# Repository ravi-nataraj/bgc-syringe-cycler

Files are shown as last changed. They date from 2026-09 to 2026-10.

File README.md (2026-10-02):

# BGC Syringe Cycler

Ten-station pneumatic fatigue cycling fixture for balloon guide catheter inflation testing. A single 5/2 solenoid valve drives ten double-acting air cylinders in parallel, each actuating a 1 mL Merit Medical Medallion syringe. Pusher and mount spacing fixes the stroke to displace ~0.6 mL per cycle.

The cycling regime is adapted from ISO 10555-4:2023 Annex B (balloon
fatigue / repeated inflation). Annex B is written for dilatation
balloons and cycles to rated burst pressure; a balloon guide catheter is specified by recommended inflation volume rather than RBP, so the fixture cycles a fixed displaced volume instead. Annex B's default of 10 cycles is likewise adapted — the fixture defaults to 20 — which the standard permits where supported by risk assessment.

Cycle timing is configurable to accommodate different test fluids —
viscous media such as contrast refill the syringe more slowly than
saline or DI water. Timing and cycle count can be set from any device over WiFi, or the fixture can be run from a single button using its DI water / saline defaults (60s on, 10s off, 20 cycles).
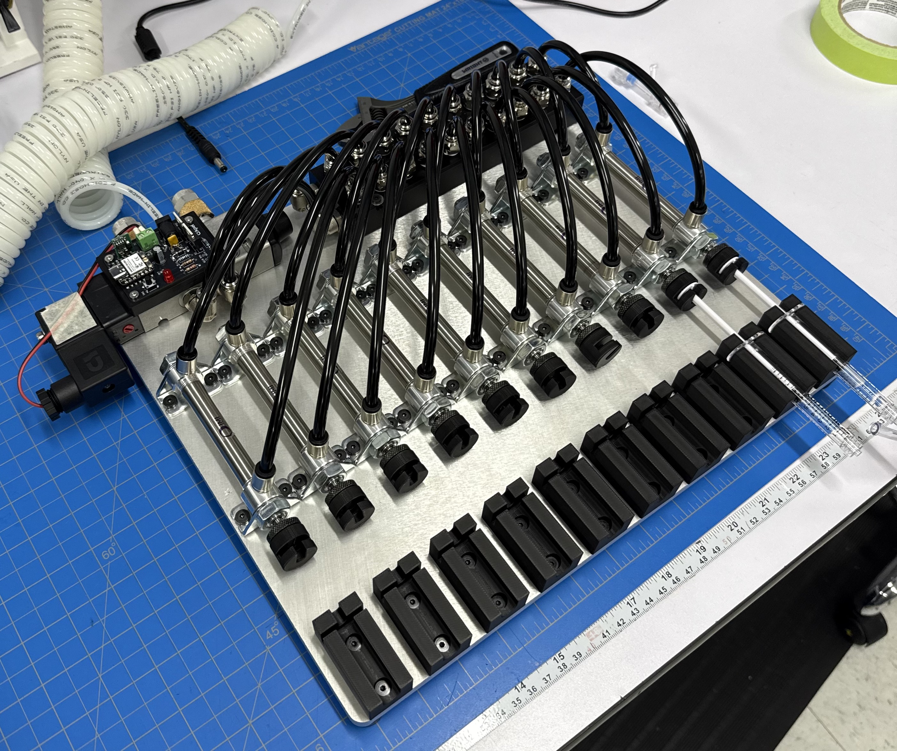
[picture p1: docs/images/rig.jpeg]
The assembled rig


---

## What it does

A run repeats one cycle: all ten cylinders extend, hold, retract, hold.
Defaults are 60 s extended, 10 s retracted, 20 cycles — about 23 minutes.

The cylinders are plumbed in parallel off two distribution manifolds, so
they move together. The controller switches a single valve coil, so
station count is a pneumatic change, not an electrical one.

---

## Running it

### From the button

Power the PCB from a 12 V DC supply (2.5 mm barrel jack, 1 A min).
Short-press the button on the control board to start. The run uses the
current settings and stops on its own. Defaults are 60 s extended,
10 s retracted, 20 cycles.

To abort mid-run, **press and hold the button for 1 second.** The valve
de-energizes immediately and the cylinders retract. A short press during
an active run does nothing, by design.

To change timing or cycle count, see the next section.

### From any device

1. Join the WiFi network **`walrus`**, password **`walrus123`**
2. Open a browser to **192.168.4.1** (add `http://` if the browser tries
to search instead of navigate).
3. Set extend time, retract time and cycle count, then **Save**
4. Press **Start run**

The page shows live status while the fixture runs: which cycle, whether
it is extended or retracted, and time remaining.

Settings lock while a run is in progress. Press **Stop and reset**, or
hold the board button, to unlock them.

Your phone will report "no internet connection" — expected, since the
board is its own access point. If your phone drops the network
automatically, tell it to stay connected when prompted.

The run continues if you disconnect. Reconnect any time to see live
status or stop the run.

### Status LED

| LED | Meaning |
|---|---|
| Off | Idle, waiting |
| Solid | Extended |
| Blinking | Retracted, between cycles |

### Defaults

Settings are held in RAM only. **Cutting power returns the fixture to
60 s / 10 s / 20 cycles**, so the next user always starts from a known
configuration. There is also a *Restore defaults* button on the web
page.

---

## Setting up the pneumatics

| Setting | Value |
|---|---|
| Supply pressure | 60 psi |
| Valve minimum | 44 psi — do not go below this |
| Valve maximum | 145 psi |
| Cylinder | 7/16" bore, 2" stroke |

Set the regulator to **60 psi**. The valve will not shift reliably below 44 psi, so watch the gauge during a ten-cylinder actuation and confirm it does not dip toward that floor. If it does, raise the supply pressure.

Stroke speed is set by the meter-out flow controls on the valve's two exhaust ports, not in firmware.

**Verify stroke before the first run.** The printed pusher bottoms
against the stationary mount, which fixes delivered volume at ~0.6 mL. Cycle once dry and confirm the pusher contacts the mount versus if plunger reaches the end of the barrel.

---

## Repository layout

```
bgc-syringe-cycler/
├── docs/
│   ├── images/                          photos and reference images
│   ├── design-notes.md                  reasoning behind major decisions
│   └── firmware-setup.md                Arduino IDE and board setup
├── firmware/
│   └── syringe_cycler_wifi_volatile.ino
├── hardware/
│   ├── gerbers/                         fabrication output, as ordered
│   ├── images/                          board renders and layout
│   ├── kicad/                           schematic, PCB, dependent libraries
│   └── snoid-swt-BOM.csv                control board bill of materials
├── mechanical/
│   ├── step/                            neutral CAD exports
│   ├── sw-pack-n-go/                    SolidWorks source
│   ├── bgc-inflation-fatigue-assy.pdf   assembly drawing
│   └── mechanical-BOM.csv               fixture bill of materials
├── .gitignore
├── LICENSE
└── README.md
```

Hardware, firmware, and mechanical source for the fixture, plus the
build and setup documentation.

---

## Control board

Custom two-layer PCB ordered from JLPCB. A XIAO ESP32-C3 sits in a socket and switches the 12 V valve coil through a logic-level MOSFET.

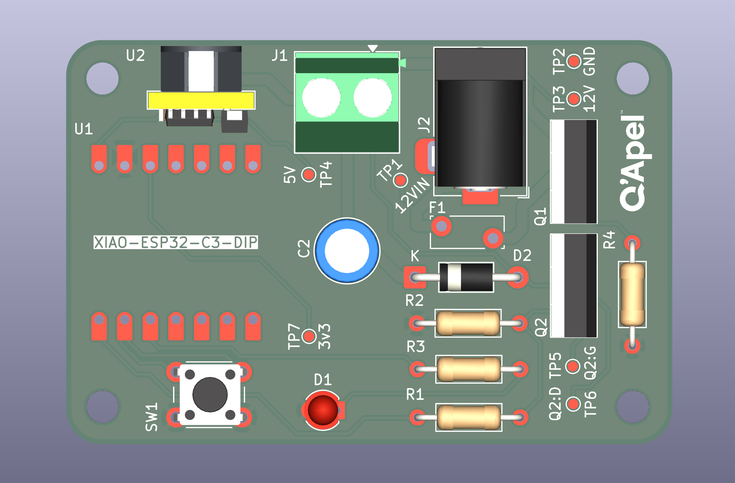
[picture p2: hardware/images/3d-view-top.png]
custom-PCB


| Function | Part |
|---|---|
| MCU | Seeed XIAO ESP32-C3, socketed |
| Valve switch | IRLZ44N, low-side |
| Flyback | 1N4007 across the coil |
| Reverse protection | IRF9540N P-channel, high-side |
| Overcurrent | 0.9 A resettable polyfuse |
| 5 V supply | OKI-78SR-5, switching, TO-220 pinout |
| Input | 12 V, 5.5 × 2.5 mm barrel jack, centre positive |

Seven test points are brought out: 12VIN, 12V, 5V, 3V3, GND, GATE and
DRAIN. See `docs/troubleshooting.md` for what to expect at each.

---

## Building the firmware

Arduino IDE with the ESP32 board package installed.

| Setting | Value |
|---|---|
| Board | XIAO_ESP32C3 |
| USB CDC On Boot | **Enabled** — required, or Serial does nothing |
| Upload spesed | 921600 |
| Serial monitor | 115200 |

Program the XIAO out of its socket, plugged straight into USB.

Serial commands also work: `E60` extend seconds, `R10` retract seconds,
`C20` cycle count, `S` start, `X` stop, `D` restore defaults.

---

## Bringing up a new board

Work through these in order.

1. **Unpowered.** Check continuity between +12 V and GND — should be
   open. A beep means a short; find it before applying power.
2. **12 V in, XIAO out of its socket.** Meter TP4 for 5.00 V.
3. **Power down, insert the XIAO, power up.** The serial banner should print and the LED should respond to the button.
4. **Connect the coil.** Listen for two clicks per cycle, one on and
   one off. No air yet.
5. **Connect air** at 60 psi and run three cycles before committing to a full run.

---

## Known limitations

- **No independent station control.** All ten cylinders actuate together from a shared supply. A single station cannot be paused, removed, or run on a different profile mid-test.
- **Ten units per run.** Each run tests ten units (one lot). A 29-unit attribute sample therefore takes three runs (10/10/9), with one station left empty on the final run.
- **Open-loop timing.** Stroke timing is fixed in firmware. The fixture does not confirm that each cylinder reached its end of travel, so a stalled or short-stroked station will not be flagged. Verify stroke by visual inspection.
- **Aggressive return stroke.** The return stroke can retract the plunger fast enough to pull the white plunger rod out of the plunger stopper. Inspect plunger assemblies periodically during long cycle runs.
- **Limited network security.** The WiFi access point is protected only by a shared password and has no user authentication or access logging. It is intended as a DV bench fixture, not a secured or validated instrument.

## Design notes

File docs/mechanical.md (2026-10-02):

# Mechanical

The fixture cycles ten 1 mL syringes in parallel for balloon guide catheter inflation fatigue testing. Each air cylinder drives a printed pusher against a syringe plunger. The barrel is held in a fixed printed holder. All ten cylinders are plumbed through two manifolds to one 5/2 solenoid valve, so every station actuates together.

The source drawing is `bgc-inflation-fatigue-assy.pdf`.
## Bill of Materials

| Item | Part Number | Description | Qty |
|---|---|---|---|
| 1 | 6498K604 | Round body air cylinder mount **[verify]** | 10 |
| 2 | 4952K126 | Foot bracket, 7/16" | 20 |
| 3 | 1ml-syringe-push | Syringe pusher (printed) | 10 |
| 4 | stationary-mount | Syringe holder (printed) | 10 |
| 5 | 5779K246 | Push-to-connect fitting | 20 |
| 6 | 92220A162 | Low-profile SHCS | 60 |
| 7 | baseplate | Baseplate (MIC-6 aluminum, machined) | 1 |
| 8 | 5469K191 | Right-angle flow manifold | 2 |
| 9 | 6124K277 | 5/2 solenoid valve | 1 |
| 10 | 7397N268 | Push-to-connect fitting | 4 |
| 11 | 53535A11 | Rubber foot | 4 |
| 12 | 7397N239 | Push-to-connect fitting | 20 |
| 13 | 90107A010 | 316 SS washer | 7 |
| 14 | 92220A157 | Low-profile SHCS | 7 |
| 15 | pcb-mount_v1 | PCB mount on solenoid (printed) | 1 |
| — | 9164K12 | Exhaust flow control, slotted screw, 1/4 NPT (not on drawing) | 2 |

Part numbers are from McMaster-Carr unless noted.
## Custom Parts

- **Baseplate:** MIC-6 aluminum, 13.976 × 11.811 in.
  - Station pitch is 1.384 ±.001.
  - 40X 10-32 holes for the cylinder brackets, 20X 10-32 for the syringe holders, and 11X 8-32 for the manifolds and valve **[verify]**.
- **Syringe holder:** FDM (PLA, ABS, or PETG), ±.020.
  - Ø5.0 mm barrel slot with a Ø9.8 mm flange pocket.
  - 2X counterbored holes for 10-32.
- **Syringe pusher:** FDM, ±.020, bore axis vertical, 4 perimeters minimum.
  - A 0.118 in slot captures the plunger flange.
  - 8-32 heat-set insert for the cylinder rod.
- **PCB mount:** FDM, 65.5 × 45.5 mm.
  - 4X M3 heat-set inserts.
  - Mounts directly to the solenoid body.

## Pneumatics

Regulated supply air feeds the 5/2 solenoid valve. The valve's two outputs each feed a manifold, one for extend and one for retract. Each manifold has 10 outlets, one per cylinder, so every cylinder has an extend line and a retract line. All air lines are 1/4" OD tubing.

Stroke speed is set by the two 9164K12 meter-out flow controls in valve exhaust ports 3 and 5. Each control sets the speed of one stroke direction.

**Setting the return speed:**

1. Retract using the manual override and find which exhaust port vents. That port controls the return.
2. Start with that port's flow control about ¾ closed. Open it a ¼ turn at a time until the cycle time is met.
3. Lock it and record the number of turns out from fully closed.
4. Run at least 200 cycles and confirm the plunger rods stay seated.

## Known Limitations

- **No independent station control.** All stations actuate together.
- **Open-loop stroke.** There are no end-of-travel sensors, so verify stroke visually.
- **Plunger separation.** A fast return can pull the white plunger rod out of the stopper. The return-side flow control limits this.
- **Uneven speed between stations.** Stations with lower friction return faster than others. Per-cylinder flow controls would even this out.
- **Tight bracket spacing.** The 10-32 bracket holes leave little clearance between cylinder brackets.
  - *Next revision:* respace the hole pattern. The station pitch and the holder pattern must change to match.
- **Printed parts.** They are uninspected at ±.020. Ream bores to fit and replace worn pushers.

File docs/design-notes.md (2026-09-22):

# Design Notes

Why the fixture is built the way it is. The README covers what it does
and how to run it; this file covers the reasoning, so that anyone
changing something knows what constraint they might be breaking.

---

## Pneumatics

### Why a 5/2 spring-return valve

The cylinder is double-acting, so it needs air on both sides — a 5/2
valve is the standard part for that. Spring return means a single coil
and a single control signal, and the fail-safe state on power loss is
retracted.

A bistable double-solenoid valve was considered. It only needs a brief
pulse to shift, so total coil-on time across a run would drop from 20
minutes to about 2 seconds, and it holds position on power loss. At
2 W the thermal argument does not matter, and retracted is the safer
fail-safe for a syringe, so spring return won.

### Air path

Shop air → filter/regulator (60 psi) → valve inlet

Valve outlet A → manifold A → ten cylinder extend ports
Valve outlet B → manifold B → ten cylinder retract ports

Both valve exhausts → muffler flow controls (meter-out, sets stroke speed)

1/4" OD trunk from valve to manifolds, 1/8" OD branches to cylinders.
Cylinder ports are 10-32.

### Why 60 psi

The valve is pilot-operated — incoming air pressure shifts the spool
and the solenoid only gates the pilot. **Below 44 psi it will not shift
reliably.**

Force is not the constraint. At 60 psi the 7/16" bore produces about
40 N gross, roughly 24 N net after meter-out back pressure, against a
worst-case plunger requirement near 12.6 N. That is around 2× margin,
and more like 4–6× for a typical balloon inflation pressure.

60 psi sits comfortably above the shift threshold while keeping force
modest. The risk to watch is **transient droop**: ten cylinders crack
open simultaneously, the manifold refills, and line pressure dips. If
the gauge dives toward 44 psi during actuation, raise supply pressure
or add a small receiver near the manifold.

### Why a 7/16" bore cylinder

Sized on force, but the real reason it works is that **delivered volume
is set by stroke length, not force**. Surplus force does not push more
fluid; it only has to exceed the resistance.

For a 1 mL syringe, 0.6 mL is about 34 mm of plunger travel. The 2"
stroke covers that with room to spare, and using two-thirds of the
stroke means a ±1 mm stop error is under 3% of dose.

**The surplus force is the hazard.** If the line ever blocks, 40 N on a
17.5 mm² plunger generates roughly 335 psi of fluid pressure — enough
to burst a small balloon or pop a luer-slip joint. Use luer lock, and
rely on the mechanical stop so the fixture delivers a fixed volume
rather than pushing until something fails.

### Why flow control on the exhaust, not the inlet

Meter-out. Throttling the exhaust gives smooth, controlled motion;
throttling the inlet gives jerky, unpredictable strokes. The two
exhaust ports also need silencing — an unmuffled 1.3 Cv valve is loud —
so muffler-flow-control units do both jobs in one body.

Note that exhaust metering controls the **aggregate** of all ten
cylinders, not each one. They will not move in perfect synchrony; the
one with least seal friction moves first. This is acceptable for this
application. Per-cylinder trim would need flow controls at each
cylinder port instead.

### Why tubing size barely matters

The cylinder's own 10-32 ports are the tightest restriction in the
system and cannot be opened up, so upsizing tubing downstream buys
nothing.

The numbers: each cylinder sweeps 0.30 in³, about 0.05 scfm if the
stroke takes a second. Ten cylinders is roughly 0.27 scfm against a
valve rated 43.1 scfm — around 160× more valve than needed.

1/4" OD on the trunk from valve to manifold, 1/8" OD on the branches,
is correct and has margin.

---

## Electronics

### Why low-side switching

The MOSFET sits between the coil and ground. Source is grounded, drain
faces the load. This is the simplest arrangement for a microcontroller
to drive, because the gate voltage is referenced to ground, which the
MCU shares.

**Source must be grounded.** Gate drive is measured gate-to-source, so
if the source floats the gate voltage means nothing. Wiring drain and
source backwards also lets the MOSFET's internal body diode conduct,
which energises the valve permanently and leaves the gate with no
authority at all.

### Why the two gate resistors are different things

**R1, 220 Ω in series.** The gate is a capacitor. At the instant the
pin goes high the gate looks like a short to ground, and without series
resistance the GPIO takes the full inrush. 3.3 V / 220 Ω = 15 mA peak,
comfortably inside spec. The cost is a switching time of a couple of
microseconds, which against a 60 second hold is nothing.

**R2, 10 kΩ pulldown.** During boot the GPIO is a floating input for a
few hundred milliseconds before firmware runs. A floating gate with no
leakage path accumulates stray charge, and if it drifts past the
threshold the valve fires. **On every power-up and every reset —
including each time new firmware is uploaded.** The pulldown gives that
charge somewhere to go.

10 kΩ is the value because it forms a divider with R1 in steady state.
1 kΩ would cost 18% of the gate drive; 10 kΩ costs 2% and still bleeds
charge fast enough.

### Why the flyback diode

The coil stores energy in a magnetic field. Switching it off abruptly
produces V = -L(di/dt), which without a path can reach several hundred
volts across a MOSFET rated for 55 V.

The diode sits **in parallel with the coil**, band toward +12 V. In
normal operation it is reverse-biased and does nothing. At switch-off
it forward-biases and the current circulates in a closed loop through
coil and diode until it decays, clamping the spike to about 12.7 V.

Installed backwards it is a direct short across the supply.

Fitting it at the coil terminals rather than on the PCB catches the
spike at its source. The board has a footprint for it either way.

### Why the P-FET is wired backwards

Reverse-polarity protection. Barrel jacks are physically identical
whether centre-positive or centre-negative, so plugging in the wrong
adapter is easy and would destroy the electrolytic and the regulator.

A series diode would work but costs 0.4–0.7 V continuously. A MOSFET
does it in a few milliohms.

**The wiring is deliberately reversed:**

| Pin | Connects to |
|---|---|
| Drain | input side, from the polyfuse |
| Source | output side, the +12 V rail |
| Gate | ground, through 10 kΩ |

Correct polarity: the body diode conducts first, lifting the source to
about 11.4 V. Gate sits at 0 V, so Vgs ≈ −11.4 V, which is solidly on
for a P-channel. The channel then shorts out its own body diode.

Reverse polarity: the body diode faces the wrong way to conduct, and
the gate ends up positive relative to source, which is off. Two
independent mechanisms both block.

**If wired the intuitive way** — source to input, drain to output — the
body diode would conduct freely on reverse polarity and the protection
would do nothing, while looking perfectly correct on the schematic.
This is the connection most likely to be "corrected" by someone who
does not know why it is like that.

### Why 0.9 A on the polyfuse

The board draws about 320 mA: 167 mA for the coil plus roughly 150 mA
at 12 V to make the XIAO's 5 V.

Sizing rule is 2–3× normal draw. 0.9 A hold gives 2.8× headroom — no
nuisance tripping — and trips at 1.8 A, a fault current the board
survives briefly.

A 1.85 A part was ordered first. It holds until 3.7 A, which is 11×
normal draw and only protects against a hard short. The 0.9 A part is
also physically smaller and uses the same 5.08 mm radial footprint.

Derating matters: at 40 °C the hold current drops to 0.75 A, at 60 °C
to 0.61 A. Still well above 320 mA.

### Why a regulator module and not a designed-in one

The OKI-78SR-5 is a switching regulator in a **three-terminal TO-220
package pin-compatible with a 7805**. It takes 7–36 V in, gives fixed
5 V out at up to 1.5 A, needs no external components, and runs at about
90% efficiency.

That combination removes three problems at once:

- **No switching layout to get wrong.** Inductor placement and feedback
  routing are already solved inside the module.
- **No trimpot.** An adjustable buck module ships at an arbitrary
  voltage, and connecting the XIAO before setting it is the single
  easiest way to destroy the board.
- **No custom footprint.** TO-220 is already in the KiCad library and
  already used for both MOSFETs.

**A linear 7805 is not an acceptable substitute.** Dropping 7 V at the
XIAO's 250–500 mA WiFi transmit peaks means 2–3.5 W in a TO-220, which
hits thermal shutdown. The symptom looks exactly like a random software
reset, which is miserable to diagnose.

### Why the XIAO is socketed

The USB port stays accessible for programming, a damaged module is a
$5 swap rather than desoldering 14 castellated pads, and the module can
move between boards.

Machined round-pin sockets rather than stamped — better contact, and
they survive repeated insertion.

**Assembly note:** plug the two 7-pin sockets onto the XIAO's own pins
first, then drop the whole assembly into the board and solder. That
guarantees the spacing matches the module even if the footprint is
slightly off.

### Why the 100 µF is where it is

Bulk decoupling on the 12 V rail. When the MOSFET turns on, the coil
demands 167 mA instantly, and that current has to travel through cable,
a barrel jack, and PCB traces — all of which have inductance. The rail
sags briefly.

The capacitor supplies that first gulp locally. Without it, a deep
enough dip trips the regulator's undervoltage lockout and brownouts the
XIAO mid-run, which presents as a random crash.

Electrolytic is correct here. Nothing measures its value and its
leakage is irrelevant — the job is cheap farads close to the load.

---

## Firmware

### Why millis() and not delay()

`delay(60000)` would freeze the processor for a minute, during which
the button is unreadable. The abort gesture could not exist.

The loop runs thousands of times per second doing three cheap things:
read the button, check whether the current state's timer has elapsed,
update the LED. Nothing blocks, so the button stays responsive through
the entire run.

The `now - stateEnteredAt` pattern is also overflow-safe. `millis()`
wraps after 49 days and unsigned subtraction still gives the correct
elapsed time across the wrap.

### Why the long press fires on threshold, not release

The abort fires the instant the hold passes one second, rather than
waiting for the button to be let go. The operator gets immediate
feedback and the valve drops the moment they have held long enough.

A flag then suppresses the short press that the release would otherwise
generate.

### Why a short press does nothing mid-run

Two different stop gestures would mean a knocked bench could end a
23-minute test at cycle 17. Stopping requires the deliberate hold.

### Why settings are not saved to flash

An earlier version used the Preferences library, so settings survived a
power cycle. That was changed deliberately.

On shared equipment, a stale setting is worse than an inconvenient one.
If someone sets 5 s / 5 s / 3 cycles for a quick check and walks away,
the next person pressing the button gets 5/5/3 without knowing. Holding
settings in RAM means **power-off always returns the fixture to
60 s / 10 s / 20 cycles**, so the button is predictable for anyone who
did not configure it.

The trade is that a non-default run has to be configured each time the
fixture is powered up. If one non-default configuration becomes the
norm, change `DEF_EXTEND` and friends at the top of the sketch and
re-flash.

### Why an access point and not a WiFi client

The board broadcasts its own network rather than joining an existing
one. No IT involvement, no credentials, no dependence on site coverage,
and the address is always **192.168.4.1** rather than whatever a router
assigns.

### Why the safe state is set first in setup()

`digitalWrite(PIN_VALVE, LOW)` runs before serial, before the button,
before anything. If the board resets mid-run the coil de-energises in
the first microseconds rather than waiting for the rest of
initialisation.

---

## Things deliberately not done

**Independent station control.** Ten cylinders run in parallel off one
valve because the test does not require staggering them. Adding it
would mean ten valves, ten MOSFETs and ten channels — the electronics
scale linearly, but nothing in the protocol asks for it.

**Closed-loop position sensing.** Reed switches on the cylinder barrels
would confirm the piston actually reached each end rather than assuming
it after a timer, and would catch a stuck cylinder during an unattended
run. The spare GPIO exists for this. It was not needed for the initial
protocol.

**Pressure logging.** A transducer on the manifold would record what
supply pressure actually does during a ten-cylinder actuation, which is
currently verified by watching a gauge.

**A discrete 555 version.** Fully designed — CMOS 555 astable at
60 s / 10 s, CD4026 counters driving seven-segment displays, all of it
running directly from 12 V with no regulator. Set aside because the
microcontroller version was already working and is far easier to
reconfigure.

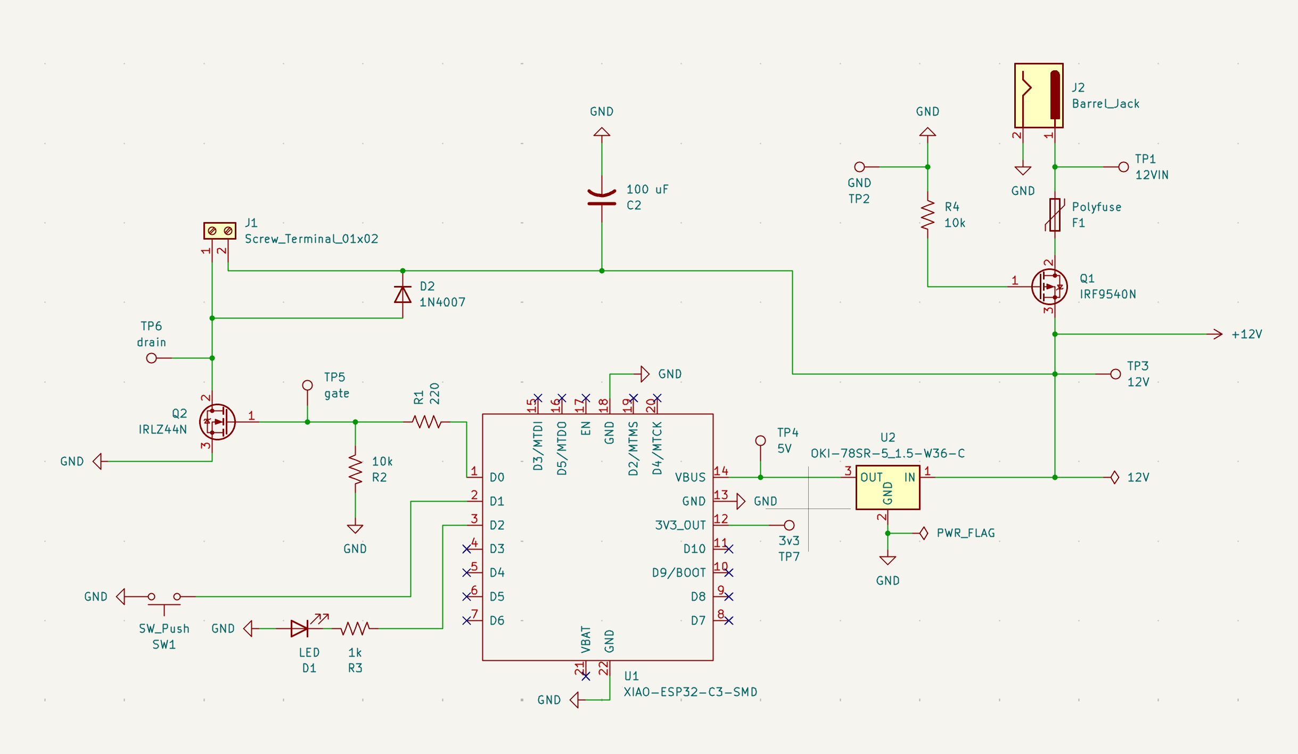
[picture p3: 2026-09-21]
hardware/images/schematic.png

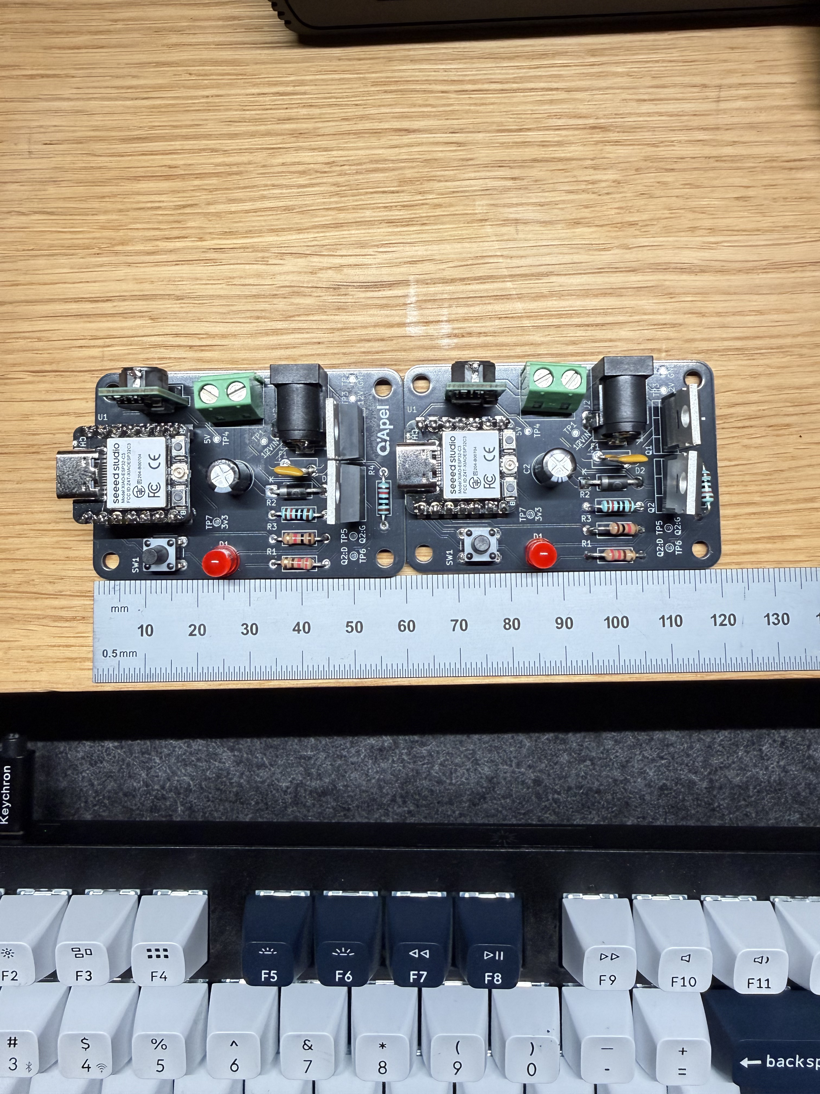
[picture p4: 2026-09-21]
hardware/images/boards-60x40-irl.jpeg

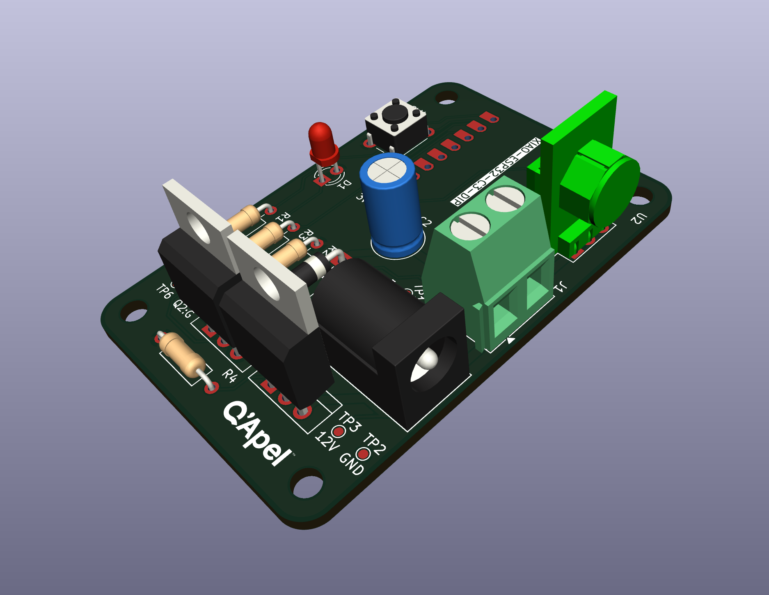
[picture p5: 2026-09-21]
hardware/images/3d-view-iso.png

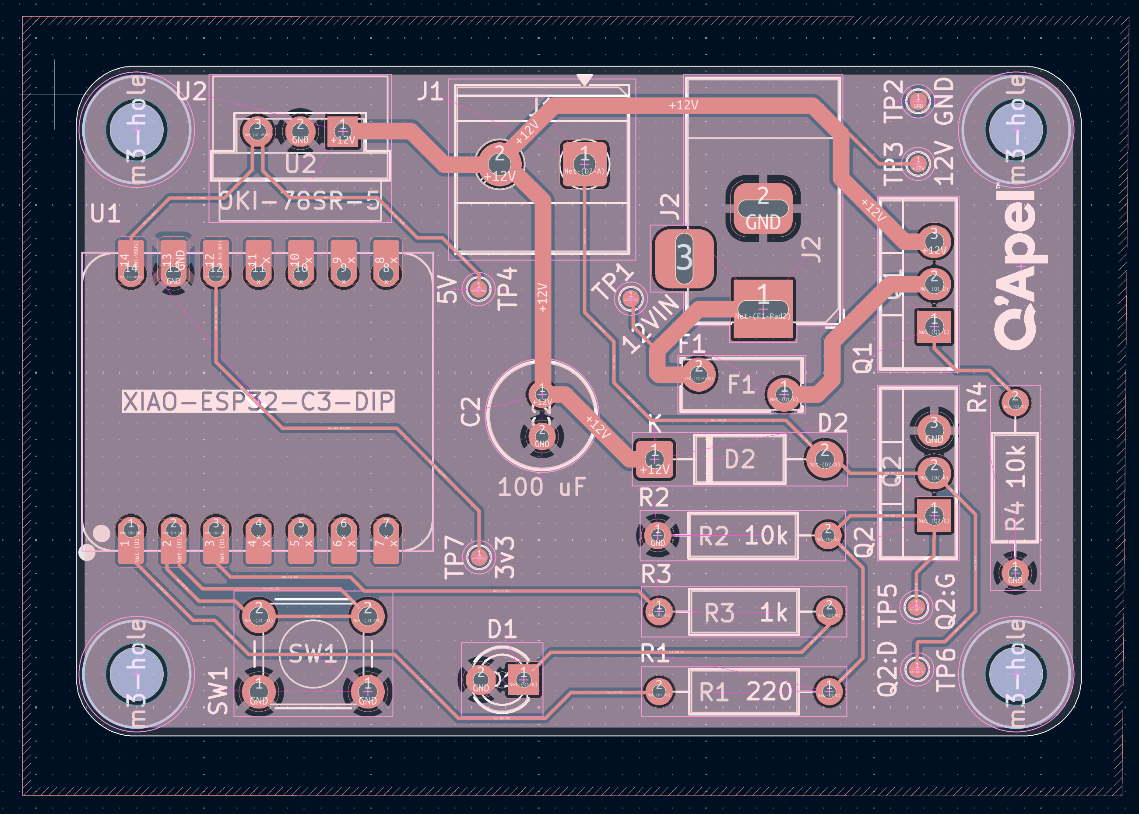
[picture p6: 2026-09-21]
hardware/images/layout.png

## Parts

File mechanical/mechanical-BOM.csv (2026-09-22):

<FONT size=10PTS>ITEM NO. | PART NUMBER | Desc1 | Desc2 | QTY.
1 | 6498K604 | Round Body Air | Cylinder Mount | 10
2 | 4952K126 | Foot Bracket | for 7/16" | 20
3 | 1ml-syringe-push | proximal syringe pusher | n | 10
4 | stationary-mount | distal syringe holder | n/a | 10
5 | 5779K246 | Push-to-Connect Tube | Fitting for Air | 20
6 | 92220A162 | Alloy Steel Low-Profile | Socket Head Screw | 60
7 | baseplate | n/a | n/a | 1
8 | 5469K191 | Anodized Aluminum Right- | Angle Flow Manifold | 2
9 | 6124K277 | Air Directional | Control Valve | 1
10 | 7397N268 | Universal-Thread Push-to- | Connect Tube Fitting | 4
11 | 53535A11 | Rubber | Foot | 4
12 | 7397N239 | Universal-Thread Push-to- | Connect Tube Fitting | 20
13 | 90107A010 | Highly Corrosion-Resistant | 316 Stainless Steel Washer | 7
14 | 92220A157 | Alloy Steel Low-Profile | Socket Head Screw | 7
15 | pcb-mount_v1 | n/a | n/a | 1

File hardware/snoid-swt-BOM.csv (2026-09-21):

Reference | Qty | Value | DNP | Exclude from BOM | Exclude from Board | Footprint | Datasheet
C2 | 1 | 100 uF |  |  |  | Capacitor_THT:CP_Radial_D8.0mm_P3.50mm
D1 | 1 | LED |  |  |  | LED_THT:LED_D3.0mm
D2 | 1 | 1N4007 |  |  |  | Diode_THT:D_DO-41_SOD81_P10.16mm_Horizontal | http://www.vishay.com/docs/88503/1n4001.pdf
F1 | 1 | Polyfuse |  |  |  | Resistor_THT:R_Axial_DIN0207_L6.3mm_D2.5mm_P10.16mm_Horizontal
J1 | 1 | Screw_Terminal_01x02 |  |  |  | TerminalBlock_Phoenix:TerminalBlock_Phoenix_MKDS-1,5-2-5.08_1x02_P5.08mm_Horizontal
J2 | 1 | Barrel_Jack |  |  |  | Connector_BarrelJack:BarrelJack_Horizontal
Q1 | 1 | IRF9540N |  |  |  | Package_TO_SOT_THT:TO-220-3_Vertical | http://www.irf.com/product-info/datasheets/data/irf9540n.pdf
Q2 | 1 | IRLZ44N |  |  |  | Package_TO_SOT_THT:TO-220-3_Vertical | http://www.irf.com/product-info/datasheets/data/irlz44n.pdf
R1 | 1 | 220 |  |  |  | Resistor_THT:R_Axial_DIN0207_L6.3mm_D2.5mm_P10.16mm_Horizontal
R2,R4 | 2 | 10k |  |  |  | Resistor_THT:R_Axial_DIN0207_L6.3mm_D2.5mm_P10.16mm_Horizontal
R3 | 1 | 1k |  |  |  | Resistor_THT:R_Axial_DIN0207_L6.3mm_D2.5mm_P10.16mm_Horizontal
SW1 | 1 | SW_Push |  |  |  | Button_Switch_THT:SW_PUSH_6mm
U1 | 1 | XIAO-ESP32-C3-SMD |  |  |  | Seeed_Studio_XIAO_Series:XIAO-ESP32-C3-DIP
U2 | 1 | OKI-78SR-5_1.5-W36-C |  |  |  | Converter_DCDC:Converter_DCDC_Murata_OKI-78SR_Vertical | https://power.murata.com/data/power/oki-78sr.pdf

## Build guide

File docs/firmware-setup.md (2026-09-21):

# Firmware Setup

How to install the toolchain and flash the XIAO ESP32-C3.

The XIAO does **not** appear in the Arduino IDE out of the box. It ships
inside Espressif's ESP32 board package, which has to be added manually.

---

## 1. Install the Arduino IDE

Download the current version from
[arduino.cc/en/software](https://www.arduino.cc/en/software) and install
it normally. Version 2.x is fine.

## 2. Add the ESP32 board manager URL
s
Arduino IDE → **Settings** (macOS: Arduino IDE → Settings; Windows:
File → Preferences).

In **Additional Boards Manager URLs**, paste:

```
https://espressif.github.io/arduino-esp32/package_esp32_index.json
```

Click OK.

> If that URL ever fails, this mirror is identical:
> `https://raw.githubusercontent.com/espressif/arduino-esp32/gh-pages/package_esp32_index.json`

## 3. Install the ESP32 package

**Tools → Board → Boards Manager**, search `esp32`, and install the
**esp32 by Espressif Systems** package.

It is a large download and takes a few minutes.

Version **2.0.8 or later** is required for the XIAO boards. Take the
latest.

## 4. Select the board

**Tools → Board → ESP32 Arduino → XIAO_ESP32C3**

That list is long and alphabetical-ish; the XIAO entries sit near the
end. If you cannot find it, the package did not install — go back to
step 3.

## 5. Set the board options

| Setting | Value | Why |
|---|---|---|
| Board | XIAO_ESP32C3 | not ESP32C3 Dev Module, not S3 |
| USB CDC On Boot | **Enabled** | required, see below |
| Upload Speed | 921600 | drop to 115200 if uploads fail partway |
| Port | the one with `usbmodem` in the name | |

**USB CDC On Boot must be Enabled.** The C3 talks to your computer over
native USB rather than a separate serial chip. With this disabled,
`Serial` output goes nowhere and the Serial Monitor stays blank, which
looks exactly like a firmware problem.

## 6. Flash it

Open `firmware/syringe_cycler_wifi_volatile.ino`.

**Program the XIAO out of its socket**, plugged straight into USB. The
control board does not need to be powered, and keeping the two separate
means a failed upload is a firmware problem rather than a wiring one.

Click Upload. Then open the Serial Monitor at **115200** and press the
board's reset button — you should see the startup banner.

---

## If something goes wrong

**"This chip is ESP32, not ESP32-S3"** (or similar mismatch)
Wrong board selected. The list contains several similarly named
entries. You want **XIAO_ESP32C3**, no suffix.

**Serial Monitor is blank**
USB CDC On Boot is Disabled. Change it and re-upload — the setting is
compiled into the sketch, so changing it alone does nothing.

**Garbled characters in Serial Monitor**
Wrong baud rate. Set the dropdown to 115200.

**Upload fails at "Connecting..."**
Hold the **BOOT** button on the XIAO, click Upload, and release once
the dots start moving. Some boards do not auto-reset into bootloader
mode reliably.

**Port does not appear**
Try a different USB-C cable. Charge-only cables carry no data and are
indistinguishable by eye. This is a more common cause than it should
be.

**XIAO_ESP32C3 is not in the board list**
The package did not install. Check the URL in Settings is exactly
right, then reopen Boards Manager and confirm esp32 shows as installed.

---

## After flashing

The fixture broadcasts a WiFi network called **`walrus`**, password
**`walrus12`**. Join it and browse to **http://192.168.4.1**.

Serial commands also work at 115200: `E60` extend seconds, `R10`
retract seconds, `C20` cycle count, `S` start, `X` stop, `D` restore
defaults.

See the main [README](../README.md) for operating instructions.

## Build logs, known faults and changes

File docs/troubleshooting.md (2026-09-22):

# Troubleshooting

## Before probing

Disconnect shop air first. The valve is spring return, so an
de-energised coil parks the cylinders retracted, but a board fault can
leave the coil energised with the cylinders extended.

Measure with 12 V connected and the board idle unless stated otherwise.

## Test points

Seven points are brought out. Values are nominal — record the readings
from a known-good board and compare against those.

| Point | Expected | Notes |
|---|---|---|
| `GND` | 0 V | Reference. Probe here first. |
| `12VIN` | 12.0 V | Supply as delivered, ahead of protection. |
| `12V` | ~11.7–12.0 V | After the IRF9540N and polyfuse. Small drop is normal. |
| `5V` | 5.0 V | OKI-78SR-5 output. Holds regardless of valve state. |
| `3V3` | 3.3 V | XIAO onboard regulator. |
| `GATE` | 0 V idle, 3.3 V energised | Driven by the ESP32 GPIO. |
| `DRAIN` | ~12 V idle, ~0 V energised | Inverts relative to `GATE`. |

`GATE` is what the firmware asked for. `DRAIN` is what the hardware did.
If `GATE` swings and `DRAIN` does not, the fault is the MOSFET or the
coil, not the firmware.

## Nothing powers on

No LED, no WiFi network.

`12VIN` at 0 V — fault is upstream. Check the supply, jack and cable.
The plug is 5.5 × 2.5 mm; a 2.1 mm plug fits loosely and makes
intermittent contact.

`12VIN` good, `12V` at 0 V — either reverse polarity (centre pin must be
positive) or the polyfuse has tripped. It resets on its own once cool,
so pull power for a minute and retest. Repeat trips mean a real
overcurrent — check for a shorted coil or a solder bridge.

`12V` good, `5V` at 0 V — regulator failed or shorted downstream.

`5V` good, `3V3` at 0 V — reseat the XIAO.

## Board runs, valve does not fire

Probe `GATE` through a cycle. If it swings 0 to 3.3 V on schedule, the
firmware is fine.

Then probe `DRAIN`:

- Stays near 12 V with `GATE` high — MOSFET is not switching. Open gate
  connection, damaged IRLZ44N, or open coil. Measure coil resistance
  with the connector off.
- Stays near 0 V regardless of `GATE` — MOSFET shorted drain-to-source.
  Replace it. The valve is permanently energised in this state.

## Valve fires, cylinders do not move

Valve clicks, no motion.

The valve needs ~44 psi to shift, so it can click without shifting at
low pressure. Confirm regulated supply is at 60 psi.

If pressure is right, check the meter-out flow controls on the exhaust
ports. Fully closed will stall the cylinders.

## Some stations weak or slow

All ten run off one valve through two manifolds, so a fault affecting
only some stations is downstream of the manifolds — kinked branch line,
loose fitting, or an unevenly set flow control.

Pull and reseat the fitting at both ends. Push-to-connect fittings that
are not fully home leak under load but hold at rest.

## Delivered volume drifting

Inspect the printed pusher and stationary mount at the affected station.

The cylinder stalls at full pressure against the printed stop every
extend stroke. PETG takes it, but creep or wear at the contact face
lengthens the stroke and changes delivered volume. Check the mount first,
heat-set inserts second.

## WiFi network not visible

The board is its own access point and does not join site WiFi.

If the network is absent, check `3V3` — the XIAO is unpowered or
unseated. If `3V3` is good, reflash. A failed upload can leave the board
powered but never reaching `WiFi.softAP()`.

## Joined but the page will not load

The address is always `192.168.4.1`.

Type `http://192.168.4.1` explicitly. Browsers assume HTTPS and will
fail rather than fall back — the board serves plain HTTP.

Phones may drop the network automatically and return to cellular. Tell
the phone to stay connected when prompted.

## Run stopped unexpectedly

If settings reverted to 60 / 10 / 20, the board lost power and
restarted. Settings are RAM only. Check the supply and the jack, not the
firmware.

If settings are intact, the run completed or was aborted. A one-second
button hold and the web Stop do the same thing.

## Serial

USB at 115200 baud. Prints each extend and retract with the cycle
number.

| Command | Effect |
|---|---|
| `E60` | Extend time, seconds |
| `R10` | Retract time, seconds |
| `C20` | Cycle count |
| `S` | Start |
| `X` | Stop and reset |
| `D` | Restore defaults |

Fastest way to confirm the state machine is running with the pneumatics
disconnected.

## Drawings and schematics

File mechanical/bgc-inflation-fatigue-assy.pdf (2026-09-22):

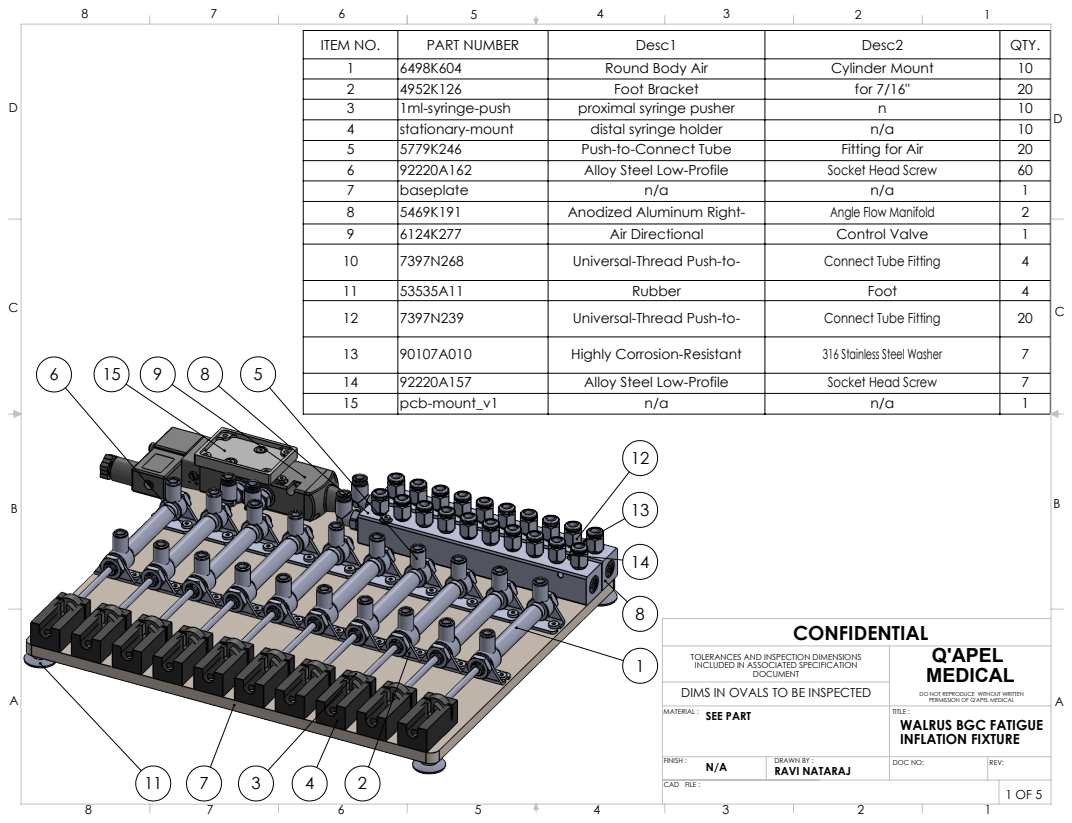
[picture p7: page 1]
FINISH :; MATERIAL :; DRAWN BY :; TITLE :; DOC NO:; REV: N/A; RAVI NATARAJ

ITEM NO. | PART NUMBER | Desc1 | Desc2 | QTY.
1 | 6498K604 | Round Body Air | Cylinder Mount | 10
2 | 4952K126 | Foot Bracket | for 7/16" | 20
3 | 1ml-syringe-push | proximal syringe pusher | n | 10
4 | stationary-mount | distal syringe holder | n/a | 10
5 | 5779K246 | Push-to-Connect Tube | Fitting for Air | 20
6 | 92220A162 | Alloy Steel Low-Profile | Socket Head Screw | 60
7 | baseplate | n/a | n/a | 1
8 | 5469K191 | Anodized Aluminum Right- | Angle Flow Manifold | 2
9 | 6124K277 | Air Directional | Control Valve | 1
10 | 7397N268 | Universal-Thread Push-to- | Connect Tube Fitting | 4
11 | 53535A11 | Rubber | Foot | 4
12 | 7397N239 | Universal-Thread Push-to- | Connect Tube Fitting | 20

13 | 90107A010 | Highly Corrosion-Resistant | 316 Stainless Steel Washer | 7
14 | 92220A157 | Alloy Steel Low-Profile | Socket Head Screw | 7
15 | pcb-mount_v1 | n/a | n/a | 1

TOLERANCES AND INSPECTION DIMENSIONS
DIMS IN OVALS TO BE INSPECTED
SEE PART

INCLUDED IN ASSOCIATED SPECIFICATION

DO NOT REPRODUCE WITHOUT WRITTEN
PERMISSION OF Q'APEL MEDICAL
WALRUS BGC FATIGUE
INFLATION FIXTURE

1 OF 5 CAD FILE :

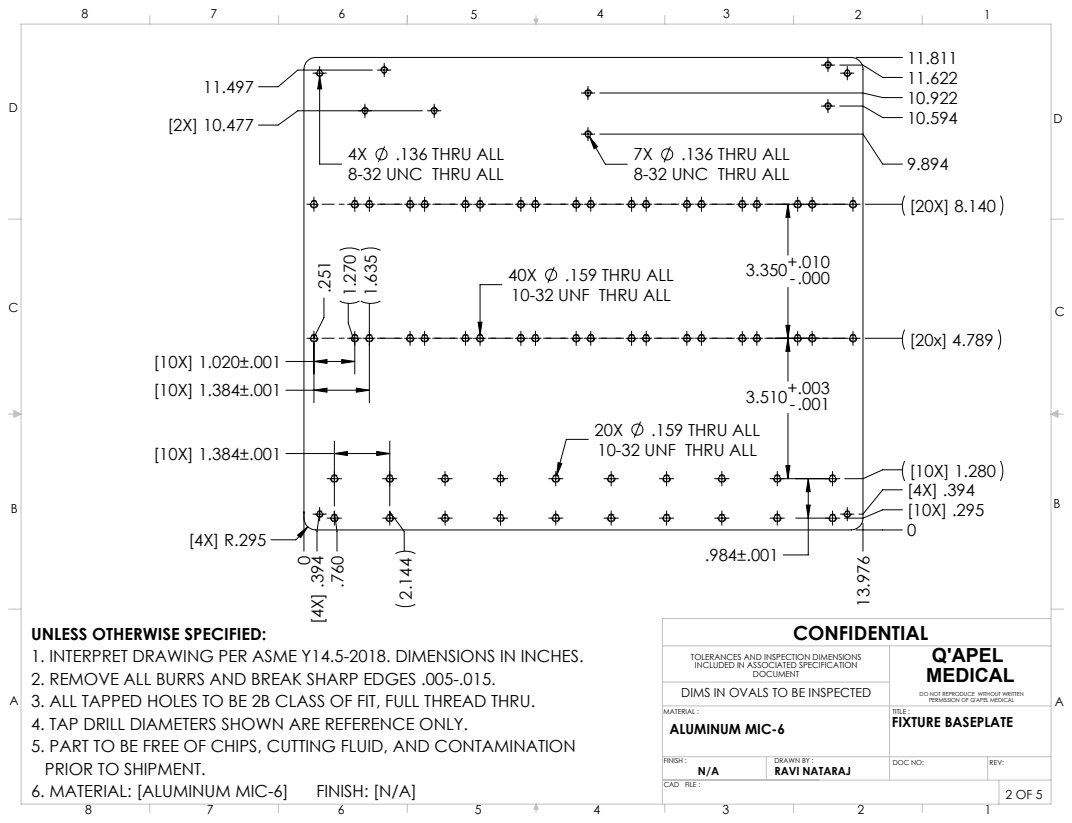
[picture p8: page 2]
.159 THRU ALL; .136 THRU ALL; 6. MATERIAL: [ALUMINUM MIC-6]; FINISH: [N/A]; FINISH :; MATERIAL :; DRAWN BY :; TITLE :; DOC NO:; REV:

8-32 UNC THRU ALL

10-32 UNF THRU ALL

UNLESS OTHERWISE SPECIFIED:
1. INTERPRET DRAWING PER ASME Y14.5-2018. DIMENSIONS IN INCHES.
2. REMOVE ALL BURRS AND BREAK SHARP EDGES .005-.015.
3. ALL TAPPED HOLES TO BE 2B CLASS OF FIT, FULL THREAD THRU.
4. TAP DRILL DIAMETERS SHOWN ARE REFERENCE ONLY.
5. PART TO BE FREE OF CHIPS, CUTTING FLUID, AND CONTAMINATION
PRIOR TO SHIPMENT.

TOLERANCES AND INSPECTION DIMENSIONS
INCLUDED IN ASSOCIATED SPECIFICATION
DIMS IN OVALS TO BE INSPECTED
ALUMINUM MIC-6

DO NOT REPRODUCE WITHOUT WRITTEN
PERMISSION OF Q'APEL MEDICAL
FIXTURE BASEPLATE

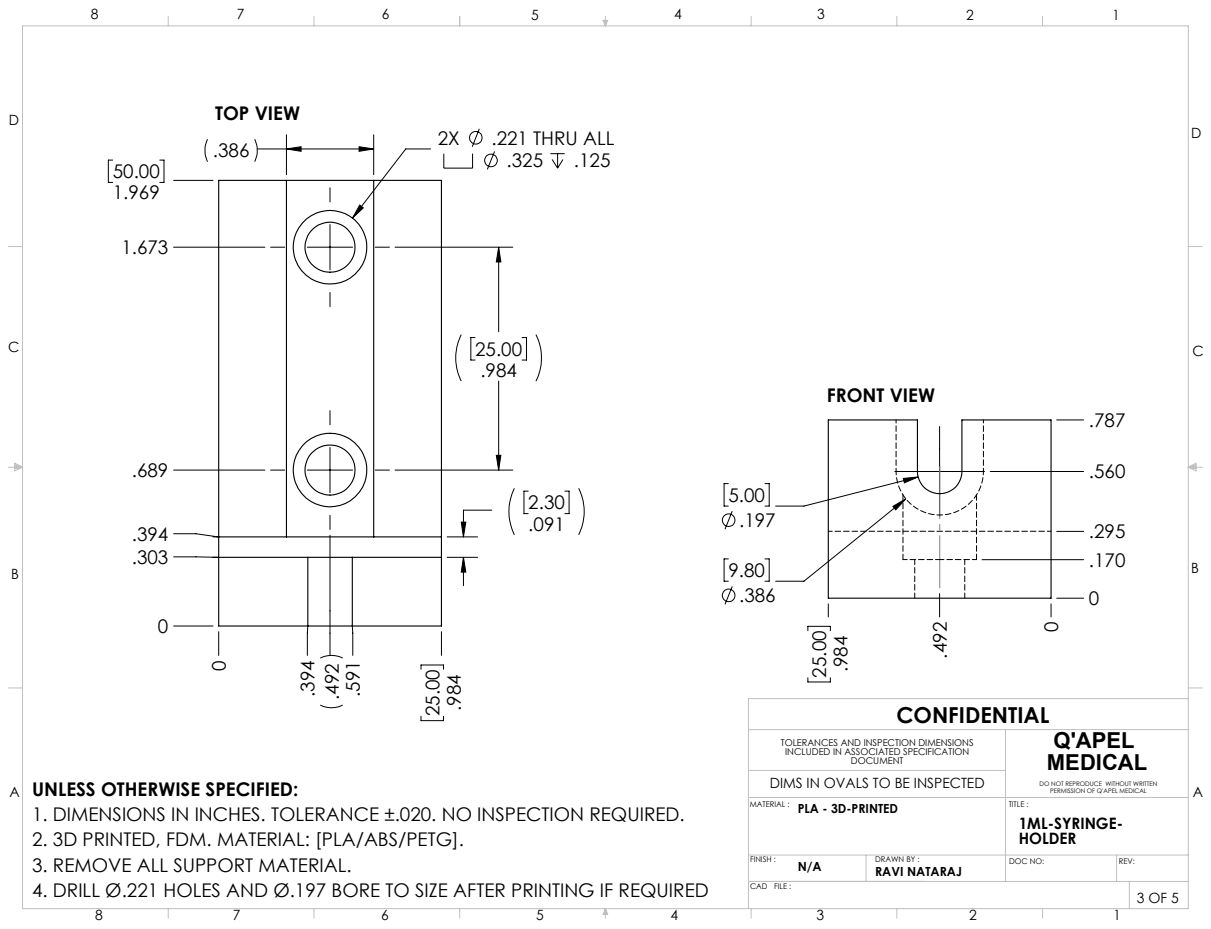
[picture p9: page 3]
.221 THRU ALL; TOP VIEW; FRONT VIEW; FINISH :; MATERIAL :; DRAWN BY :; TITLE :; DOC NO:; REV: N/A

TOLERANCES AND INSPECTION DIMENSIONS
INCLUDED IN ASSOCIATED SPECIFICATION
DIMS IN OVALS TO BE INSPECTED
PLA - 3D-PRINTED

UNLESS OTHERWISE SPECIFIED:
1. DIMENSIONS IN INCHES. TOLERANCE ±.020. NO INSPECTION REQUIRED.
2. 3D PRINTED, FDM. MATERIAL: [PLA/ABS/PETG].
3. REMOVE ALL SUPPORT MATERIAL.
4. DRILL Ø.221 HOLES AND Ø.197 BORE TO SIZE AFTER PRINTING IF REQUIRED

DO NOT REPRODUCE WITHOUT WRITTEN
PERMISSION OF Q'APEL MEDICAL
1ML-SYRINGE-
HOLDER

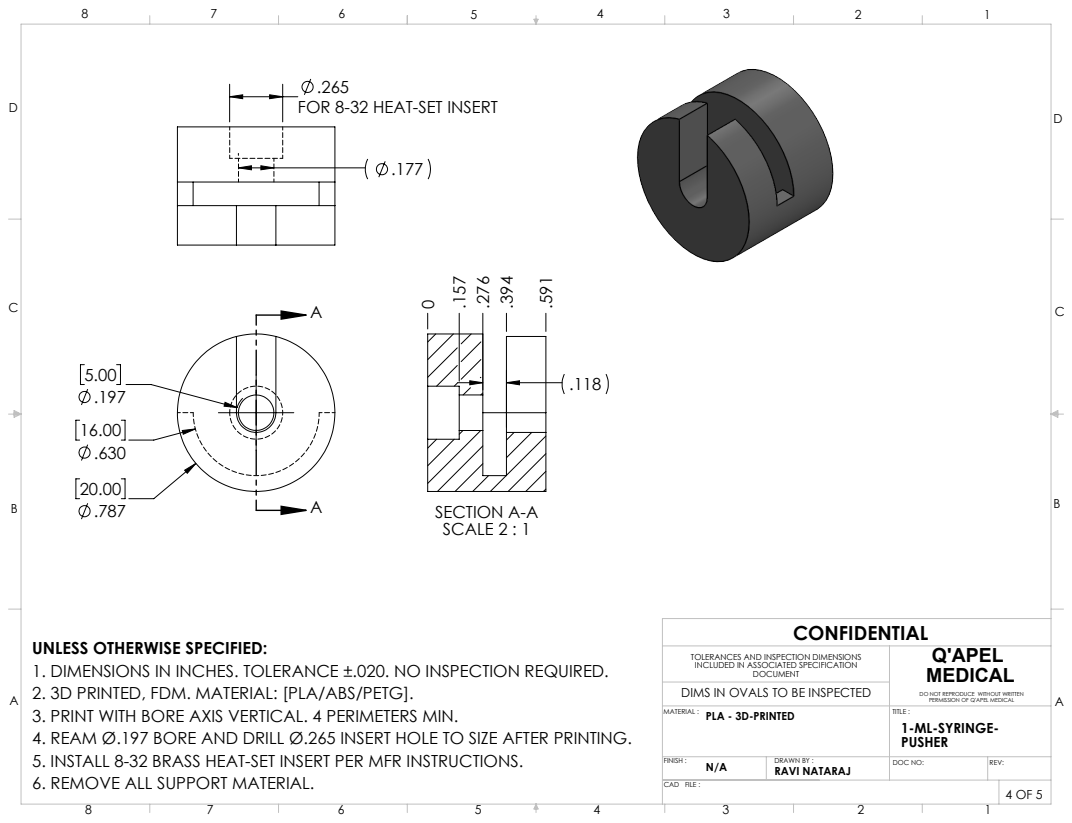
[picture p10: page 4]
SECTION A-A SCALE 2 : 1; FINISH :; MATERIAL :; DRAWN BY :; TITLE :; DOC NO:; REV: N/A

FOR 8-32 HEAT-SET INSERT

UNLESS OTHERWISE SPECIFIED:
1. DIMENSIONS IN INCHES. TOLERANCE ±.020. NO INSPECTION REQUIRED.
2. 3D PRINTED, FDM. MATERIAL: [PLA/ABS/PETG].
3. PRINT WITH BORE AXIS VERTICAL. 4 PERIMETERS MIN.
4. REAM Ø.197 BORE AND DRILL Ø.265 INSERT HOLE TO SIZE AFTER PRINTING.
5. INSTALL 8-32 BRASS HEAT-SET INSERT PER MFR INSTRUCTIONS.
6. REMOVE ALL SUPPORT MATERIAL.

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

DO NOT REPRODUCE WITHOUT WRITTEN
PERMISSION OF Q'APEL MEDICAL
1-ML-SYRINGE-
PUSHER

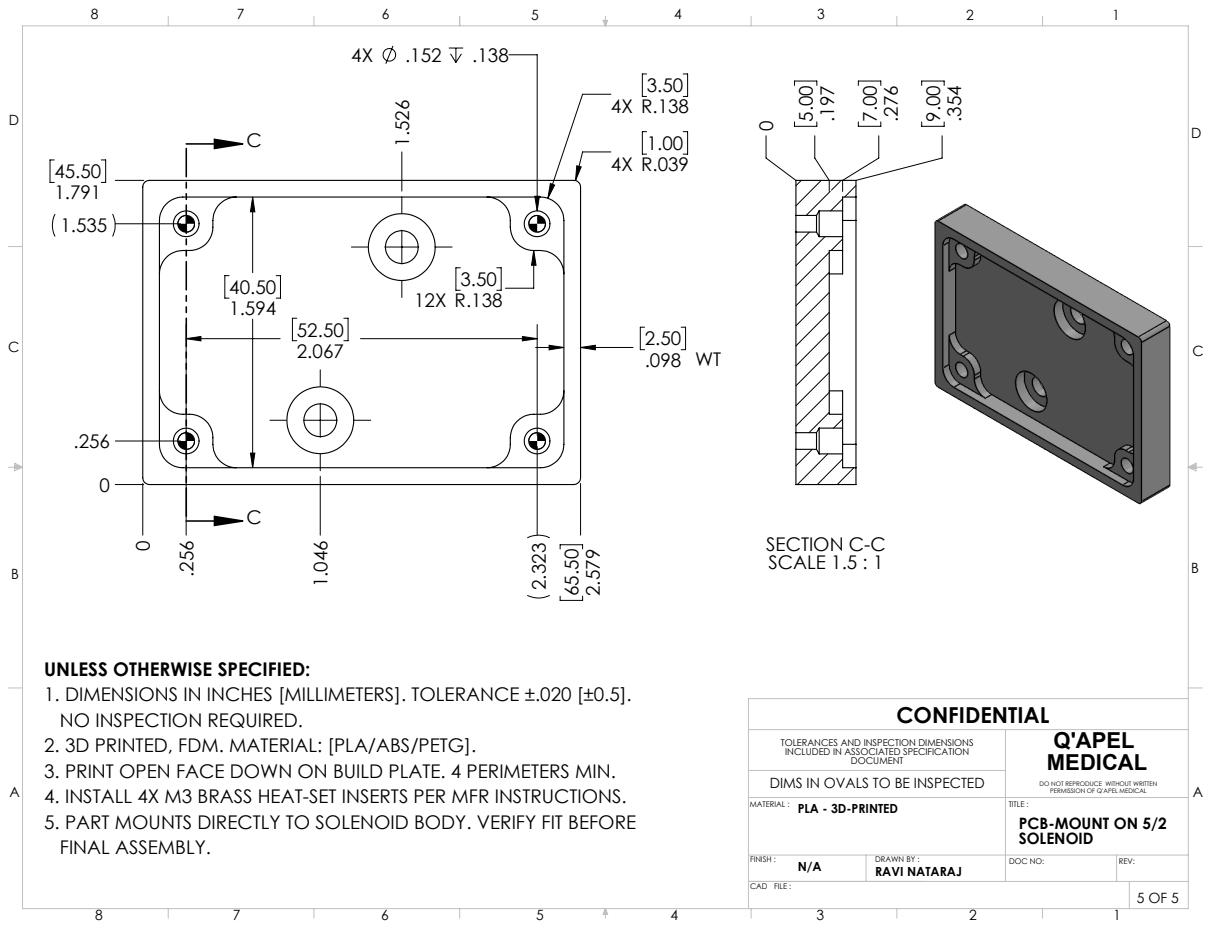
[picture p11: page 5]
SECTION C-C SCALE 1.5 : 1; FINISH :; MATERIAL :; DRAWN BY :; TITLE :; DOC NO:; REV: N/A

UNLESS OTHERWISE SPECIFIED:
1. DIMENSIONS IN INCHES [MILLIMETERS]. TOLERANCE ±.020 [±0.5].
NO INSPECTION REQUIRED.
2. 3D PRINTED, FDM. MATERIAL: [PLA/ABS/PETG].
3. PRINT OPEN FACE DOWN ON BUILD PLATE. 4 PERIMETERS MIN.
4. INSTALL 4X M3 BRASS HEAT-SET INSERTS PER MFR INSTRUCTIONS.
5. PART MOUNTS DIRECTLY TO SOLENOID BODY. VERIFY FIT BEFORE
FINAL ASSEMBLY.

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

DO NOT REPRODUCE WITHOUT WRITTEN
PERMISSION OF Q'APEL MEDICAL
PCB-MOUNT ON 5/2
SOLENOID

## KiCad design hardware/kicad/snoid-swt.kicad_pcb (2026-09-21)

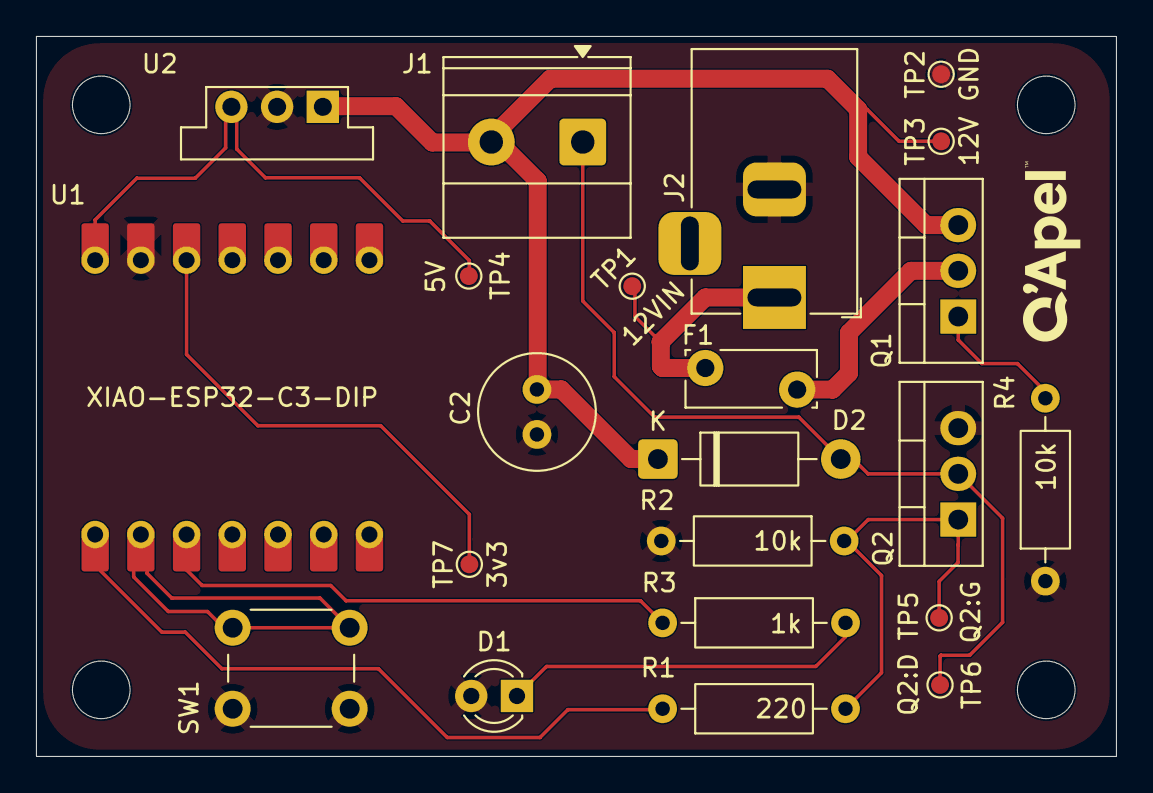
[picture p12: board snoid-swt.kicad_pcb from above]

Board: 2 copper layers, 60.0 x 40.0 mm, 26 parts (0 on the bottom side), 13 nets.

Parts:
C2: 100 uF; C_Radial_D6.3mm_H11.0mm_P2.50mm
D1: LED; LED_D3.0mm
D2: 1N4007; D_DO-41_SOD81_P10.16mm_Horizontal
F1: Polyfuse; Fuse_Bourns_MF-RG300
J1: Screw_Terminal_01x02; TerminalBlock_Phoenix_MKDS-1,5-2-5.08_1x02_P5.08mm_Horizont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
J2: Barrel_Jack; BarrelJack_Horizontal
Q1: IRF9540N; TO-220-3_Vertical
Q2: IRLZ44N; TO-220-3_Vertical
R1: 220; R_Axial_DIN0207_L6.3mm_D2.5mm_P10.16mm_Horizontal
R2, R4: 10k; R_Axial_DIN0207_L6.3mm_D2.5mm_P10.16mm_Horizontal
R3: 1k; R_Axial_DIN0207_L6.3mm_D2.5mm_P10.16mm_Horizontal
SW1: SW_Push; SW_PUSH_6mm
TP1: 12VIN; TestPoint_Pad_D1.0mm
TP2: GND; TestPoint_Pad_D1.0mm
TP3: 12V; TestPoint_Pad_D1.0mm
TP4: 5V; TestPoint_Pad_D1.0mm
TP5: Q2:G; TestPoint_Pad_D1.0mm
TP6: Q2:D; TestPoint_Pad_D1.0mm
TP7: 3v3; TestPoint_Pad_D1.0mm
U1: XIAO-ESP32-C3-DIP
U2: OKI-78SR-5; Converter_DCDC_Murata_OKI-78SR_Vertical
m3-hole, m3-hole#2, m3-hole#3, m3-hole#4: MountingHole_3.2mm_M3

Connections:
+12V: C2.1, D2.1 (K), J1.2, Q1.3 (S), TP3.1 (1_1), U2.1 (IN)
GND: C2.2, D1.2 (A), J2.2, Q2.3 (S), R2.1, R4.1, SW1.1, TP2.1 (1_1), U1.13 (GND), U2.2 (GND)
unnamed: D1.1 (K), R3.2
unnamed: D2.2 (A), J1.1, Q2.2 (D), TP6.1 (1_1)
unnamed: F1.2, J2.1, TP1.1 (1_1)
unnamed: F1.1, Q1.2 (D)
unnamed: Q1.1 (G), R4.2
unnamed: Q2.1 (G), R1.1, R2.2, TP5.1 (1_1)
unnamed: TP7.1 (1_1), U1.12 (3V3_OUT)
unnamed: R1.2, U1.1 (D0)
unnamed: SW1.2, U1.2 (D1)
unnamed: R3.1, U1.3 (D2)
unnamed: TP4.1 (1_1), U1.14 (VBUS), U2.3 (OUT)

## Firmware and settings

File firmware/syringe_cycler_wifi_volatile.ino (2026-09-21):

/*
 * ============================================================
 *  SYRINGE CYCLER  -  configurable over WiFi
 *  Seeed XIAO ESP32-C3
 * ============================================================
 *
 *  HOW TO USE
 *    1. Power the board.
 *    2. On a phone or laptop, join the WiFi network:
 *          SSID     : walrus
 *          password : walrus123
 *    3. Open a browser at   http://192.168.4.1
 *    4. Set extend time, retract time and cycle count. Save.
 *    5. Press Start on the page, or the button on the board.
 *
 *  Settings are held in RAM only. Pulling power or pressing reset
 *  returns the fixture to its defaults of 60 s / 10 s / 20 cycles,
 *  so the next person always starts from a known configuration.
 *
 *  Settings lock while a run is in progress. Long-press the board
 *  button, or press Stop on the page, to unlock.
 *
 *  SERIAL COMMANDS (115200)
 *    E60   extend seconds       S   start
 *    R10   retract seconds      X   stop / reset
 *    C20   cycle count          D   restore defaults
 *
 *  ARDUINO IDE
 *    Board           : XIAO_ESP32C3
 *    USB CDC On Boot : Enabled
 * ============================================================
 */

#include <WiFi.h>
#include <WebServer.h>

// ---------------- pins ----------------
const uint8_t PIN_VALVE  = D0;
const uint8_t PIN_BUTTON = D1;
const uint8_t PIN_LED    = D2;

// ---------------- wifi ----------------
const char *AP_SSID = "walrus";        
const char *AP_PASS = "walrus123";      // WPA2 needs 8+ chars, or "" for open

WebServer server(80);

// ---------------- settings ----------------
// These are the power-on defaults. Nothing is written to flash, so
// cutting power or pressing reset restores these values.
const uint16_t DEF_EXTEND  = 60;    // seconds extended
const uint16_t DEF_RETRACT = 10;    // seconds retracted
const uint16_t DEF_CYCLES  = 20;    // cycles per run

uint16_t extendSec   = DEF_EXTEND;
uint16_t retractSec  = DEF_RETRACT;
uint16_t totalCycles = DEF_CYCLES;

const uint16_t MIN_SEC = 1, MAX_SEC = 600;
const uint16_t MIN_CYC = 1, MAX_CYC = 999;

// ---------------- timing ----------------
const unsigned long DEBOUNCE_MS   = 30;
const unsigned long LONG_PRESS_MS = 1000;
const unsigned long BLINK_MS      = 500;

// ---------------- state ----------------
enum State { IDLE, EXTEND_HOLD, RETRACT_HOLD };
State state = IDLE;

unsigned long stateEnteredAt = 0;
unsigned long runStartedAt   = 0;
uint16_t      cycleCount     = 0;

bool          rawPrev      = HIGH;
bool          stableLevel  = HIGH;
unsigned long lastBounceAt = 0;
unsigned long pressStartAt = 0;
bool          longFired    = false;
bool          shortPress   = false;
bool          longPress    = false;

char    serialBuf[16];
uint8_t serialLen = 0;

bool isRunning() { return state != IDLE; }

// ============================================================
//  core machine
// ============================================================
void setValve(bool on) { digitalWrite(PIN_VALVE, on ? HIGH : LOW); }

void enterState(State s) {
  state = s;
  stateEnteredAt = millis();
}

unsigned long extendMs()  { return (unsigned long)extendSec  * 1000UL; }
unsigned long retractMs() { return (unsigned long)retractSec * 1000UL; }

void startRun() {
  cycleCount   = 0;
  runStartedAt = millis();
  Serial.println(F(">>> RUN STARTED"));
  setValve(true);
  enterState(EXTEND_HOLD);
}

void stopRun(const char *why) {
  setValve(false);
  Serial.print(F("!!! STOP: "));
  Serial.println(why);
  cycleCount = 0;
  enterState(IDLE);
}

uint16_t clampU(long v, uint16_t lo, uint16_t hi) {
  if (v < (long)lo) return lo;
  if (v > (long)hi) return hi;
  return (uint16_t)v;
}

unsigned long remainingSec() {
  if (!isRunning()) return 0;
  unsigned long inState  = (millis() - stateEnteredAt) / 1000UL;
  unsigned long thisLeft = (state == EXTEND_HOLD ? extendSec : retractSec);
  thisLeft = (inState >= thisLeft) ? 0 : thisLeft - inState;
  unsigned long full = (unsigned long)(totalCycles - cycleCount - 1) *
                       (extendSec + retractSec);
  if (state == EXTEND_HOLD) full += retractSec;
  return thisLeft + full;
}

const char *stateName() {
  switch (state) {
    case EXTEND_HOLD:  return "EXTENDED";
    case RETRACT_HOLD: return "RETRACTED";
    default:           return "IDLE";
  }
}

// ============================================================
//  web page
// ============================================================
const char PAGE_HTML[] PROGMEM = R"HTML(<!DOCTYPE html><html><head>
<meta charset="utf-8"><meta name="viewport" content="width=device-width,initial-scale=1">
<title>Syringe Cycler</title><style>
body{font-family:system-ui,-apple-system,Segoe UI,Helvetica,Arial,sans-serif;
margin:0 auto;padding:20px;background:#f6f7f9;color:#1d2939;max-width:460px}
h1{font-size:20px;margin:8px 0 4px}
.sub{color:#667085;font-size:13px;margin-bottom:20px}
.card{background:#fff;border:1px solid #e4e7ec;border-radius:12px;padding:18px;margin-bottom:16px}
label{display:block;font-size:13px;font-weight:600;margin:14px 0 6px}
input{width:100%;padding:12px;font-size:17px;border:1px solid #d0d5dd;
border-radius:8px;box-sizing:border-box}
input:disabled{background:#f2f4f7;color:#98a2b3}
button{width:100%;padding:14px;font-size:16px;font-weight:600;border:0;
border-radius:8px;margin-top:14px;cursor:pointer}
.save{background:#344054;color:#fff}
.start{background:#067647;color:#fff}
.stop{background:#b42318;color:#fff}
button:disabled{background:#d0d5dd;color:#98a2b3}
#st{font-size:15px;line-height:1.7}
.big{font-size:26px;font-weight:700}
.dot{display:inline-block;width:10px;height:10px;border-radius:50%;
margin-right:8px;vertical-align:middle}
.hint{font-size:12px;color:#667085;margin-top:10px}
</style></head><body>
<h1>Syringe Cycler</h1>
<div class="sub">fixture control</div>

<div class="card"><div id="st">connecting...</div></div>

<div class="card">
<label>Extend time (seconds)</label>
<input id="e" type="number" min="1" max="600">
<label>Retract time (seconds)</label>
<input id="r" type="number" min="1" max="600">
<label>Number of cycles</label>
<input id="c" type="number" min="1" max="999">
<button class="save" id="bs" onclick="save()">Save settings</button>
<button class="save" id="bd" onclick="go('/defaults')">Restore defaults</button>
<div class="hint">Settings lock while a run is in progress.<br>
Power-off resets to 60 s / 10 s / 20 cycles.</div>
</div>

<div class="card">
<button class="start" id="bg" onclick="go('/start')">Start run</button>
<button class="stop" onclick="go('/stop')">Stop and reset</button>
</div>

<script>
let editing=false;
['e','r','c'].forEach(i=>{
  let el=document.getElementById(i);
  el.addEventListener('focus',()=>editing=true);
  el.addEventListener('blur',()=>editing=false);
});
function fmt(s){let m=Math.floor(s/60),x=s%60;return m+"m "+String(x).padStart(2,'0')+"s";}
function poll(){
  fetch('/status').then(r=>r.json()).then(d=>{
    let col=d.running?(d.state=="EXTENDED"?"#067647":"#b45309"):"#98a2b3";
    let h='<span class="dot" style="background:'+col+'"></span><b>'+d.state+'</b>';
    if(d.running){
      h+='<div class="big">cycle '+d.cycle+' / '+d.total+'</div>';
      h+='<div>'+fmt(d.remain)+' remaining</div>';
    }else{
      h+='<div class="big">Ready</div>';
      h+='<div>'+d.total+' cycles &middot; '+d.ext+'s / '+d.ret+'s</div>';
    }
    document.getElementById('st').innerHTML=h;
    ['e','r','c'].forEach(i=>document.getElementById(i).disabled=d.running);
    document.getElementById('bs').disabled=d.running;
    document.getElementById('bd').disabled=d.running;
    document.getElementById('bg').disabled=d.running;
    if(!editing){
      document.getElementById('e').value=d.ext;
      document.getElementById('r').value=d.ret;
      document.getElementById('c').value=d.total;
    }
  }).catch(()=>{document.getElementById('st').innerHTML='connection lost';});
}
function save(){
  fetch('/set?e='+document.getElementById('e').value
       +'&r='+document.getElementById('r').value
       +'&c='+document.getElementById('c').value).then(poll);
}
function go(u){fetch(u).then(poll);}
setInterval(poll,1000); poll();
</script></body></html>)HTML";

// ============================================================
//  handlers
// ============================================================
void handleRoot() { server.send_P(200, "text/html", PAGE_HTML); }

void handleStatus() {
  char buf[220];
  snprintf(buf, sizeof(buf),
    "{\"state\":\"%s\",\"running\":%s,\"cycle\":%u,\"total\":%u,"
    "\"remain\":%lu,\"ext\":%u,\"ret\":%u}",
    stateName(), isRunning() ? "true" : "false",
    (unsigned)(cycleCount + (isRunning() ? 1 : 0)),
    totalCycles, remainingSec(), extendSec, retractSec);
  server.send(200, "application/json", buf);
}

void handleSet() {
  if (isRunning()) { server.send(409, "text/plain", "run in progress"); return; }
  if (server.hasArg("e")) extendSec   = clampU(server.arg("e").toInt(), MIN_SEC, MAX_SEC);
  if (server.hasArg("r")) retractSec  = clampU(server.arg("r").toInt(), MIN_SEC, MAX_SEC);
  if (server.hasArg("c")) totalCycles = clampU(server.arg("c").toInt(), MIN_CYC, MAX_CYC);
 
  Serial.printf("settings: %us / %us x %u\n", extendSec, retractSec, totalCycles);
  server.send(200, "text/plain", "ok");
}

void handleDefaults() {
  if (isRunning()) { server.send(409, "text/plain", "run in progress"); return; }
  extendSec   = DEF_EXTEND;
  retractSec  = DEF_RETRACT;
  totalCycles = DEF_CYCLES;
  Serial.println(F("settings restored to defaults"));
  server.send(200, "text/plain", "ok");
}

void handleStart() {
  if (!isRunning()) startRun();
  server.send(200, "text/plain", "ok");
}

void handleStop() {
  stopRun("web");
  server.send(200, "text/plain", "ok");
}

// ============================================================
//  button + led
// ============================================================
void pollButton(unsigned long now) {
  shortPress = false;
  longPress  = false;

  bool raw = digitalRead(PIN_BUTTON);
  if (raw != rawPrev) { rawPrev = raw; lastBounceAt = now; }

  if (now - lastBounceAt >= DEBOUNCE_MS && raw != stableLevel) {
    stableLevel = raw;
    if (stableLevel == LOW) { pressStartAt = now; longFired = false; }
    else if (!longFired)    { shortPress = true; }
  }

  if (stableLevel == LOW && !longFired &&
      now - pressStartAt >= LONG_PRESS_MS) {
    longFired = true;
    longPress = true;
  }
}

void updateLed(unsigned long now) {
  switch (state) {
    case IDLE:         digitalWrite(PIN_LED, LOW);  break;
    case EXTEND_HOLD:  digitalWrite(PIN_LED, HIGH); break;
    case RETRACT_HOLD: digitalWrite(PIN_LED, (now / BLINK_MS) % 2); break;
  }
}

// ============================================================
//  serial
// ============================================================
void showSettings() {
  Serial.printf("settings: extend %us  retract %us  cycles %u  [%s]\n",
                extendSec, retractSec, totalCycles, stateName());
}

void handleSerialLine(char *line) {
  char c = toupper(line[0]);
  long v = atol(line + 1);
  switch (c) {
    case 'E': if (!isRunning()) { extendSec   = clampU(v, MIN_SEC, MAX_SEC); } break;
    case 'R': if (!isRunning()) { retractSec  = clampU(v, MIN_SEC, MAX_SEC); } break;
    case 'C': if (!isRunning()) { totalCycles = clampU(v, MIN_CYC, MAX_CYC); } break;
    case 'S': if (!isRunning()) startRun(); break;
    case 'X': stopRun("serial"); break;
    case 'D': if (!isRunning()) { extendSec = DEF_EXTEND;
                                  retractSec = DEF_RETRACT;
                                  totalCycles = DEF_CYCLES; } break;
    default:  break;
  }
  showSettings();
}

void pollSerial() {
  while (Serial.available()) {
    char ch = Serial.read();
    if (ch == '\n' || ch == '\r') {
      if (serialLen) { serialBuf[serialLen] = 0; handleSerialLine(serialBuf); serialLen = 0; }
    } else if (serialLen < sizeof(serialBuf) - 1) {
      serialBuf[serialLen++] = ch;
    }
  }
}

// ============================================================
void setup() {
  pinMode(PIN_VALVE, OUTPUT);
  digitalWrite(PIN_VALVE, LOW);          // safe state before anything else
  pinMode(PIN_BUTTON, INPUT_PULLUP);
  pinMode(PIN_LED, OUTPUT);
  digitalWrite(PIN_LED, LOW);

  Serial.begin(115200);
  delay(400);

  WiFi.mode(WIFI_AP);
  WiFi.softAP(AP_SSID, AP_PASS);

  server.on("/",       handleRoot);
  server.on("/status", handleStatus);
  server.on("/set",    handleSet);
  server.on("/defaults", handleDefaults);
  server.on("/start",  handleStart);
  server.on("/stop",   handleStop);
  server.begin();

  Serial.println();
  Serial.println(F("========================================"));
  Serial.println(F("  SYRINGE CYCLER"));
  Serial.print  (F("  join wifi : ")); Serial.println(AP_SSID);
  Serial.print  (F("  password  : ")); Serial.println(AP_PASS);
  Serial.print  (F("  browse to : http://"));
  Serial.println(WiFi.softAPIP());
  showSettings();
  Serial.println(F("========================================"));

  enterState(IDLE);
}

void loop() {
  unsigned long now = millis();

  server.handleClient();
  pollSerial();
  pollButton(now);

  if (longPress) {
    stopRun("button held");
    updateLed(now);
    return;
  }

  switch (state) {

    case IDLE:
      if (shortPress) startRun();
      break;

    case EXTEND_HOLD:
      if (now - stateEnteredAt >= extendMs()) {
        setValve(false);
        Serial.printf("cycle %u/%u : retract\n", cycleCount + 1, totalCycles);
        enterState(RETRACT_HOLD);
      }
      break;

    case RETRACT_HOLD:
      if (now - stateEnteredAt >= retractMs()) {
        cycleCount++;
        if (cycleCount >= totalCycles) {
          setValve(false);
          Serial.printf("<<< COMPLETE - %u cycles in %lu s\n",
                        totalCycles, (now - runStartedAt) / 1000UL);
          cycleCount = 0;
          enterState(IDLE);
        } else {
          setValve(true);
          Serial.printf("cycle %u/%u : extend\n", cycleCount + 1, totalCycles);
          enterState(EXTEND_HOLD);
        }
      }
      break;
  }

  updateLed(now);
}

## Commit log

2026-09-21 Update README to specify SEEED XIAO ESP32-C3
2026-09-21 Add gitignore
    [snoid-swt-BOM.csv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]
2026-09-22 Added mechanical assembly + drawing
2026-09-22 Added mechanical BOM CSV
    [mechanical-BOM.csv]
2026-09-22 Added mechanical folder directory, and moved SW/STEP/DWG files into respective folders
    [mechanical-BOM.csv, snoid-swt-BOM.csv]
